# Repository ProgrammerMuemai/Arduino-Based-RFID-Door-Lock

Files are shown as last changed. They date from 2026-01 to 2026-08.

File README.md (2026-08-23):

# Arduino-Based-RFID-Door-Lock
ดูวีดีโอการทำงานได้ที่
https://youtu.be/LQMiO3PaC_U

# RFID Door Lock System with Arduino UNO

ระบบควบคุมประตูด้วยบัตร RFID โดยใช้ **Arduino UNO**, **MFRC522**, **LCD I2C** และ **Relay / SSR**

ระบบตรวจสอบสิทธิ์จาก UID ของบัตร RFID รองรับบัตรได้หลายใบ พร้อมปุ่ม **LOCK / UNLOCK แบบ Manual** และระบบ **Auto Lock หลังปลดล็อก 5 วินาที**

---

## 🔐 Features

- รองรับบัตร RFID หลายใบด้วย UID แบบ 4-byte
- ตรวจสอบสิทธิ์จาก UID ของบัตร
- แสดงสถานะผ่านจอ LCD 16x2 แบบ I2C
- ควบคุมกลอนประตูแม่เหล็ก (Magnetic Door Lock)
- รองรับ Relay / SSR
- ปุ่มกด LOCK / UNLOCK แบบ Manual
- ปุ่มต่อแบบ Pull-down
- มีระบบ Debounce ป้องกันปุ่มเด้ง
- กด UNLOCK แล้วล็อกกลับอัตโนมัติภายใน 5 วินาที
- แตะบัตรที่ได้รับอนุญาตแล้วปลดล็อก 5 วินาที
- LCD แสดงเวลานับถอยหลังจนกว่าจะ LOCK
- สามารถกด LOCK เพื่อขัดจังหวะและล็อกทันทีได้
- สามารถกด UNLOCK ซ้ำเพื่อเริ่มนับเวลา 5 วินาทีใหม่
- สามารถแตะบัตร RFID ขณะกำลังนับถอยหลังได้
- แตะบัตรที่ได้รับอนุญาตซ้ำ จะเริ่มนับ 5 วินาทีใหม่
- บัตรที่ไม่ได้รับอนุญาตจะไม่สามารถปลดล็อกได้
- แสดง UID ทั้ง HEX และ DEC ผ่าน Serial Monitor
- เพิ่มบัตรใหม่ใน `ALLOW_LIST` ได้ง่าย
- ใช้ `millis()` สำหรับ Auto Lock ทำให้ระบบไม่ค้างระหว่างนับเวลา

---

## 🧰 Hardware Required

- Arduino UNO
- MFRC522 RFID Reader
- RFID Card / Key Tag
- LCD 16x2 I2C
- Relay Module หรือ SSR
- Magnetic Door Lock 12V
- Buzzer
- Push Button x2
  - LOCK
  - UNLOCK
- Resistor สำหรับ Pull-down ปุ่มกด
- Power Supply 12V
- สาย Jumper
- Breadboard หรือ PCB ตามรูปแบบงาน

> สำหรับ Magnetic Door Lock ควรเลือก Power Supply ที่มีกระแสเพียงพอกับกลอนประตูที่ใช้งานจริง  
> โดยทั่วไปแนะนำอย่างน้อยประมาณ **12V 3A** หากใช้ร่วมกับอุปกรณ์อื่นในระบบ

---

## ⚠️ Important: MFRC522 Voltage

MFRC522 ใช้แรงดันไฟประมาณ **3.3V**

ควรต่อ:

```text
MFRC522 VCC -> Arduino 3.3V
```

ไม่ควรต่อ VCC ของ MFRC522 เข้ากับ 5V โดยตรง

---

## 🔌 Pin Configuration

| Device | Arduino UNO Pin |
|---|---:|
| MFRC522 SDA / SS | D10 |
| MFRC522 RST | D9 |
| MFRC522 MOSI | D11 |
| MFRC522 MISO | D12 |
| MFRC522 SCK | D13 |
| Relay / SSR | D2 |
| Buzzer | D3 |
| Unlock Button | D4 |
| Lock Button | D5 |
| LCD SDA | A4 |
| LCD SCL | A5 |

---

## 📡 MFRC522 Wiring

| MFRC522 | Arduino UNO |
|---|---|
| SDA / SS | D10 |
| SCK | D13 |
| MOSI | D11 |
| MISO | D12 |
| IRQ | Not Connected |
| GND | GND |
| RST | D9 |
| 3.3V | 3.3V |

---

## 🖥 LCD I2C Wiring

| LCD I2C | Arduino UNO |
|---|---|
| VCC | 5V |
| GND | GND |
| SDA | A4 |
| SCL | A5 |

LCD ที่ใช้ในโปรเจกต์นี้:

```cpp
LiquidCrystal_I2C lcd(0x27, 16, 2);
```

ดังนั้น I2C Address คือ:

```text
0x27
```

หากจอไม่แสดงผล อาจต้องตรวจสอบ I2C Address ของจอที่ใช้งานจริง

---

## 🔘 Push Button Wiring

ระบบใช้ปุ่มกดแบบ **Pull-down**

สถานะของปุ่ม:

```text
ไม่กด = LOW
กด     = HIGH
```

ขาที่ใช้:

```text
UNLOCK Button -> D4
LOCK Button   -> D5
```

ตัวอย่างการต่อปุ่ม:

```text
5V
 |
 |
[ Push Button ]
 |
 +---------- Arduino Input
 |
[ 10KΩ ]
 |
GND
```

---

## ⚡ Relay / SSR Logic

ระบบปัจจุบันกำหนด Logic ของขา D2 ดังนี้:

```cpp
#define RELAY_LOCK   LOW
#define RELAY_UNLOCK HIGH
```

ดังนั้น:

| Arduino D2 | Door State |
|---|---|
| LOW | 🔒 LOCK |
| HIGH | 🔓 UNLOCK |

หรือสรุปง่าย ๆ:

```text
LOW  = LOCK
HIGH = UNLOCK
```

> **หมายเหตุ:** Relay หรือ SSR แต่ละรุ่นอาจมี Logic การ Trigger แตกต่างกัน  
> ควรทดสอบโมดูลที่ใช้งานจริงก่อนเชื่อมต่อกับ Magnetic Door Lock

---

## 🧠 How It Works

### 1. เปิดเครื่อง

เมื่อเปิดระบบ Arduino จะกำหนดสถานะเริ่มต้นเป็น:

```text
LOCK
```

และ LCD จะแสดง:

```text
    WELCOME
TAP CARD TO OPEN
```

---

### 2. แตะบัตร RFID

Arduino จะอ่าน UID ของบัตรจาก MFRC522 และนำไปเปรียบเทียบกับรายการ:

```cpp
ALLOW_LIST
```

---

### 3. ถ้าบัตรได้รับอนุญาต

ระบบจะ:

1. ปลดล็อกประตู
2. ส่งเสียง Beep
3. แสดงสถานะ `UNLOCK` บน LCD
4. เริ่มนับถอยหลัง 5 วินาที
5. เมื่อครบเวลา ระบบจะ LOCK อัตโนมัติ
6. LCD กลับไปหน้า WELCOME

ตัวอย่าง:

```text
  >> UNLOCK <<
Lock in: 5 sec
```

จากนั้นจะนับ:

```text
Lock in: 4 sec
Lock in: 3 sec
Lock in: 2 sec
Lock in: 1 sec
```

เมื่อครบเวลา:

```text
LOCK
```

และกลับไป:

```text
    WELCOME
TAP CARD TO OPEN
```

---

### 4. ถ้าบัตรไม่ได้รับอนุญาต

ระบบจะ:

- ไม่ปลดล็อกประตู
- ส่งเสียงเตือน 2 ครั้ง
- แสดงข้อความบน LCD

```text
 ACCESS DENIED!
 INVALID CARD
```

จากนั้นกลับไปหน้า WELCOME

---

## ⏱ Auto Lock System

เวลาปลดล็อกถูกกำหนดไว้ที่:

```cpp
const unsigned long UNLOCK_TIME = 5000;
```

ค่า `5000` หมายถึง:

```text
5000 milliseconds = 5 seconds
```

หากต้องการปลดล็อก 10 วินาที สามารถเปลี่ยนเป็น:

```cpp
const unsigned long UNLOCK_TIME = 10000;
```

---

## 🔄 Non-Blocking Countdown

ระบบใช้ `millis()` สำหรับนับเวลาแทนการใช้:

```cpp
delay(5000);
```

ข้อดีคือ Arduino ยังสามารถทำงานอื่นได้ระหว่างนับเวลา เช่น:

- อ่าน RFID
- อ่านปุ่ม LOCK
- อ่านปุ่ม UNLOCK
- อัปเดต LCD
- ตรวจสอบ Auto Lock

ทำให้ระบบตอบสนองได้ตลอดเวลา

---

## 🔘 Manual LOCK Button

เมื่อกดปุ่ม LOCK:

```text
D5 = HIGH
```

ระบบจะ LOCK ทันที

แม้ว่าขณะนั้นระบบกำลังนับถอยหลัง 5 วินาทีอยู่ก็ตาม

ตัวอย่าง:

```text
UNLOCK
5 sec
4 sec
```

หากกด LOCK:

```text
LOCK
```

ทันทีโดยไม่ต้องรอให้ครบ 5 วินาที

---

## 🔓 Manual UNLOCK Button

เมื่อกดปุ่ม UNLOCK:

```text
D4 = HIGH
```

ระบบจะ:

1. UNLOCK
2. เริ่มนับเวลา 5 วินาที
3. LCD แสดง Countdown
4. LOCK อัตโนมัติเมื่อครบเวลา

หากกด UNLOCK ซ้ำระหว่างที่กำลังปลดล็อก:

```text
5 sec
4 sec
3 sec
```

ระบบจะเริ่มนับใหม่:

```text
5 sec
```

---

## 💳 RFID During Unlock Countdown

ระหว่างที่ประตูกำลัง UNLOCK ระบบยังสามารถอ่าน RFID ได้

ตัวอย่าง:

```text
UNLOCK
Lock in: 3 sec
```

หากแตะบัตรที่ได้รับอนุญาตอีกครั้ง ระบบจะเริ่มนับใหม่:

```text
UNLOCK
Lock in: 5 sec
```

---

## 🔑 Authorized RFID Card

บัตรที่กำหนดไว้ในระบบปัจจุบัน:

### HEX

```text
C0 58 BE 13
```

### DEC

```text
192 88 190 19
```

ในโค้ดจะเขียนเป็น:

```cpp
const byte ALLOW_LIST[][4] = {

  {192, 88, 190, 19},

};
```

---

## ➕ How to Add New RFID Card

### Step 1

เชื่อมต่อ Arduino UNO กับคอมพิวเตอร์

---

### Step 2

เปิด Arduino IDE และเปิด:

```text
Tools -> Serial Monitor
```

ตั้ง Baud Rate เป็น:

```text
9600
```

---

### Step 3

แตะบัตร RFID ที่ต้องการเพิ่ม

Serial Monitor จะแสดงประมาณ:

```text
UID HEX = C0 58 BE 13
UID DEC = 192 88 190 19
```

---

### Step 4

นำค่า DEC ไปเพิ่มใน `ALLOW_LIST`

ตัวอย่างเพิ่ม 3 ใบ:

```cpp
const byte ALLOW_LIST[][4] = {

  {192, 88, 190, 19},     // Card 1
  {12, 34, 56, 78},       // Card 2
  {100, 120, 130, 140}    // Card 3

};
```

ไม่จำเป็นต้องแก้ค่า `ALLOW_COUNT` เพราะโปรแกรมจะคำนวณจำนวนบัตรให้อัตโนมัติ:

```cpp
const byte ALLOW_COUNT =
  sizeof(ALLOW_LIST) / sizeof(ALLOW_LIST[0]);
```

---

## 🖥 Serial Monitor

ตั้ง Serial Monitor ที่:

```text
9600 baud
```

ตัวอย่างเมื่อแตะบัตร:

```text
----------------------------
UID HEX = C0 58 BE 13
UID DEC = 192 88 190 19
ACCESS = GRANTED
DOOR = UNLOCK
```

เมื่อครบ 5 วินาที:

```text
AUTO LOCK AFTER 5 SEC
DOOR = LOCK
```

หากเป็นบัตรที่ไม่ได้รับอนุญาต:

```text
UID HEX = XX XX XX XX
UID DEC = XXX XXX XXX XXX
ACCESS = DENIED
```

---

## 📚 Required Arduino Libraries

โปรเจกต์นี้ใช้ Library ดังต่อไปนี้:

### MFRC522

```cpp
#include <MFRC522.h>
```

สามารถติดตั้งผ่าน Arduino IDE:

```text
Sketch
-> Include Library
-> Manage Libraries
```

ค้นหา:

```text
MFRC522
```

---

### LiquidCrystal I2C

```cpp
#include <LiquidCrystal_I2C.h>
```

ค้นหาใน Library Manager:

```text
LiquidCrystal I2C
```

---

### SPI

```cpp
#include <SPI.h>
```

เป็น Library มาตรฐานของ Arduino

---

### Wire

```cpp
#include <Wire.h>
```

เป็น Library มาตรฐานของ Arduino

---

## 📋 System Logic

| Event | Result |
|---|---|
| Power ON | 🔒 LOCK |
| Authorized RFID Card | 🔓 UNLOCK 5 sec |
| Unauthorized RFID Card | ❌ ACCESS DENIED |
| Press UNLOCK | 🔓 UNLOCK 5 sec |
| Press LOCK | 🔒 LOCK immediately |
| Unlock timeout | 🔒 AUTO LOCK |
| Authorized card during countdown | 🔄 Restart 5 sec |
| UNLOCK button during countdown | 🔄 Restart 5 sec |
| LOCK button during countdown | 🔒 LOCK immediately |

---

## 🔒 Default Safety State

เมื่อ Arduino เปิดเครื่อง ระบบจะกำหนดประตูเป็น:

```text
LOCK
```

ก่อนเริ่มต้น RFID และ LCD

ตัวอย่าง Logic:

```cpp
digitalWrite(RELAY, RELAY_LOCK);
```

โดย:

```cpp
#define RELAY_LOCK LOW
```

ดังนั้นระบบจะเริ่มต้นในสถานะ LOCK เสมอตาม Logic ของฮาร์ดแวร์ชุดนี้

---

## 🛠 Troubleshooting

### RFID อ่านบัตรไม่ได้

ตรวจสอบ:

- MFRC522 ใช้ไฟ 3.3V
- SDA ต่อ D10
- RST ต่อ D9
- MOSI ต่อ D11
- MISO ต่อ D12
- SCK ต่อ D13
- GND ต้องต่อร่วมกัน

---

### LCD ไม่แสดงผล

ตรวจสอบ:

```text
SDA -> A4
SCL -> A5
```

และตรวจสอบ I2C Address

ค่าปัจจุบัน:

```text
0x27
```

---

### Relay / SSR ทำงานกลับด้าน

หากระบบจริงทำงานตรงข้าม เช่น:

```text
LOW  = UNLOCK
HIGH = LOCK
```

ให้สลับค่า:

```cpp
#define RELAY_LOCK   HIGH
#define RELAY_UNLOCK LOW
```

---

### ปุ่ม LOCK / UNLOCK ทำงานสลับกัน

ตรวจสอบว่าสายต่อถูกต้อง:

```text
UNLOCK -> D4
LOCK   -> D5
```

---

### RFID หลุดหรืออ่านไม่ได้เมื่อกลอนทำงาน

กลอนแม่เหล็กและวงจร Relay อาจสร้าง Noise รบกวน Arduino หรือ MFRC522

แนวทางแก้ไข:

- แยกสายไฟกลอนออกจากสายสัญญาณ RFID
- ใช้ Power Supply ที่มีกระแสเพียงพอ
- ต่อ GND ให้เหมาะสม
- เพิ่ม Capacitor ใกล้ Arduino / MFRC522
- หากใช้ Relay กับโหลด DC แบบขดลวด ควรมีวงจรป้องกันแรงดันย้อนกลับตามชนิดวงจร
- หลีกเลี่ยงการเดินสาย MFRC522 ใกล้สายกำลังของ Magnetic Lock

---

## ⚠️ Security Note

ระบบนี้ตรวจสอบสิทธิ์จาก **UID ของบัตร RFID**

เหมาะสำหรับ:

- โปรเจกต์ Arduino
- ระบบทดลอง
- ห้อง Workshop
- ตู้เก็บอุปกรณ์
- ระบบควบคุมการเข้าออกที่ไม่ต้องการ Security ระดับสูง

UID เพียงอย่างเดียวไม่ควรถูกใช้เป็นระบบรักษาความปลอดภัยระดับสูง เนื่องจากบัตร RFID บางประเภทสามารถจำลองหรือคัดลอก UID ได้

---

## 🚀 Future Improvements

สามารถพัฒนาระบบเพิ่มเติมได้ เช่น:

- เพิ่ม Admin Card
- เพิ่มโหมด Add / Delete Card
- บันทึก UID ลง EEPROM
- เพิ่ม RTC สำหรับบันทึกเวลาเข้าออก
- เพิ่ม SD Card สำหรับเก็บ Log
- เพิ่ม ESP32
- เชื่อมต่อ Wi-Fi
- แจ้งเตือนผ่าน LINE / Telegram
- เชื่อมต่อ Home Assistant
- เพิ่ม Keypad
- เพิ่ม Fingerprint Sensor
- เพิ่ม Door Sensor
- เพิ่ม Exit Button
- เพิ่มระบบตรวจสอบว่าประตูปิดจริงหรือไม่
- เพิ่มระบบ Web Dashboard

---

## 👨‍💻 Author

Developed by **MengDIY**

Arduino RFID Door Lock System

---

## 📄 License

This project is intended for educational and DIY purposes.

You are free to study, modify, and improve the project for your own use.

---

⭐ หากโปรเจกต์นี้มีประโยชน์ สามารถกด **Star** Repository เพื่อสนับสนุนโปรเจกต์ได้

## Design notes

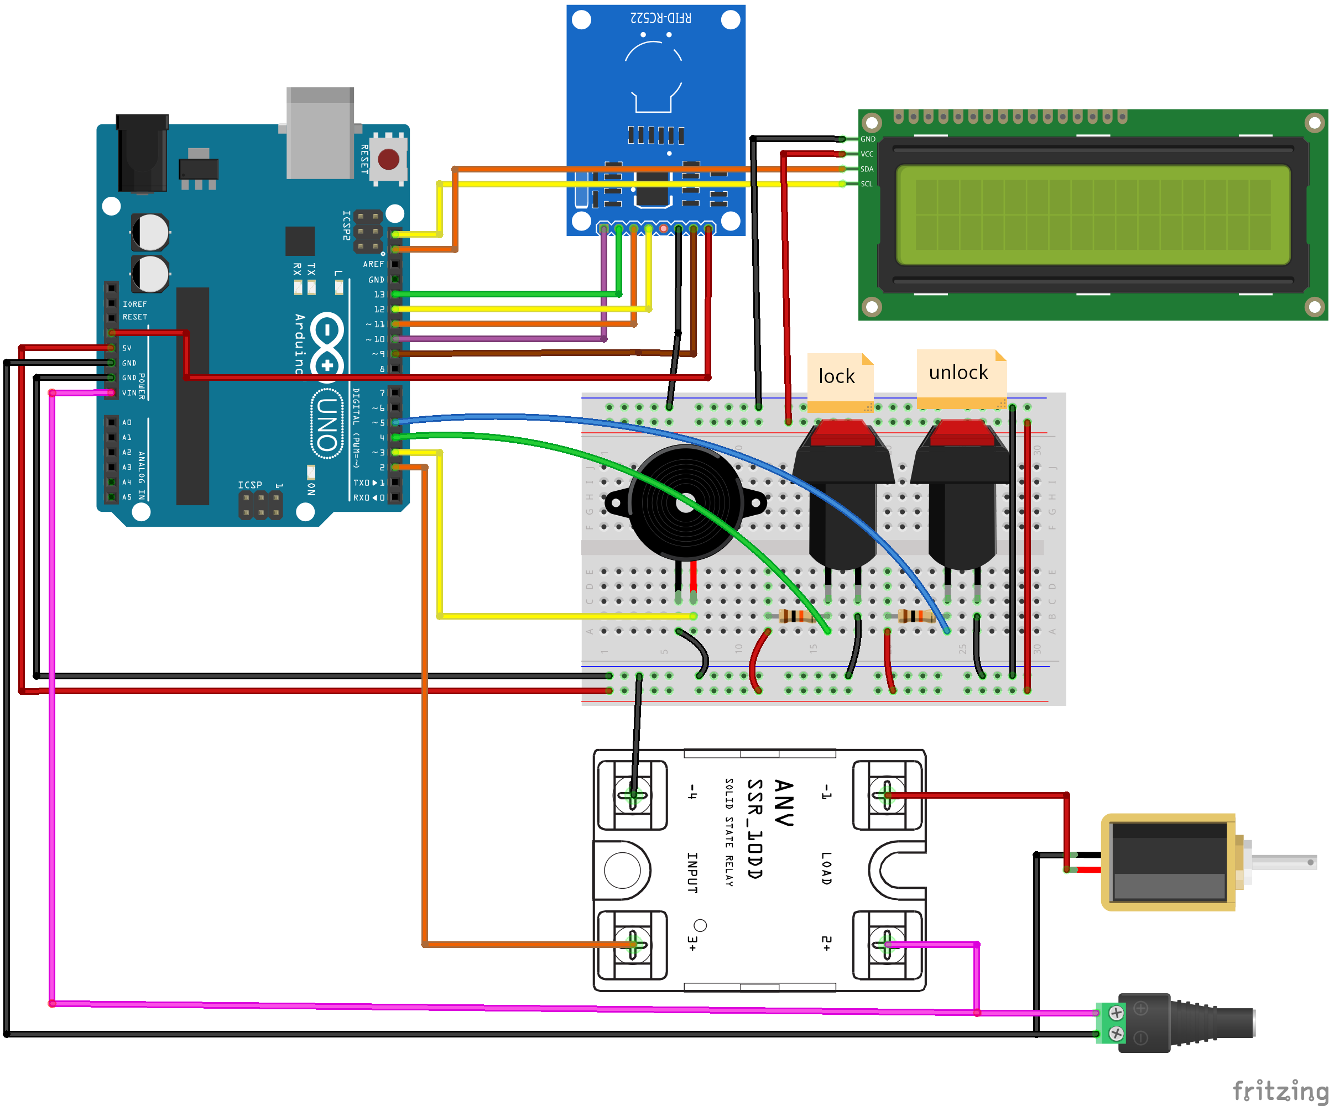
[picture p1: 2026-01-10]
Circuit/circuit_bb.png

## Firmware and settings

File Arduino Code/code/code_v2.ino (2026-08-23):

// ===================== ไลบรารี =====================
#include <SPI.h>
#include <MFRC522.h>
#include <Wire.h>
#include <LiquidCrystal_I2C.h>

// ===================== กำหนดขา =====================
#define SS_PIN 10
#define RST_PIN 9

#define RELAY 2
#define BUZZER 3

// จากการทดสอบปุ่มของคุณ
#define UNLOCK 4
#define LOCK   5

// =====================================================
//                 LOGIC ของ SSR
// =====================================================
// LOW  = LOCK
// HIGH = UNLOCK
#define RELAY_LOCK   LOW
#define RELAY_UNLOCK HIGH

// ===================== Object =====================
LiquidCrystal_I2C lcd(0x27, 16, 2);
MFRC522 rfid(SS_PIN, RST_PIN);

// =====================================================
//               UID บัตรที่อนุญาต
// =====================================================
// HEX = C0 58 BE 13
// DEC = 192 88 190 19

const byte ALLOW_LIST[][4] = {

  {192, 88, 190, 19},

  // เพิ่มบัตรใบอื่นได้ เช่น
  // {12, 34, 56, 78},
  // {100, 120, 130, 140},

};

const byte ALLOW_COUNT =
  sizeof(ALLOW_LIST) / sizeof(ALLOW_LIST[0]);

// =====================================================
//                  เวลา UNLOCK
// =====================================================

const unsigned long UNLOCK_TIME = 5000;

unsigned long unlockStartMs = 0;

bool doorUnlocked = false;

// =====================================================
//                 Boot / Debounce
// =====================================================

unsigned long bootMs = 0;

const unsigned long BOOT_IGNORE_MS = 1000;
const unsigned long DEBOUNCE_MS = 120;

unsigned long lastBtnMs = 0;

bool lastLock = LOW;
bool lastUnlock = LOW;

// สำหรับอัปเดตเลข Countdown
int lastCountdown = -1;

// =====================================================
//                  ตรวจสอบ UID
// =====================================================

bool isAllowedUID(const byte *uid, byte size) {

  // UID ต้องเป็น 4 byte
  if (size != 4) {
    return false;
  }

  // ตรวจทุกบัตรใน Allow List
  for (byte card = 0; card < ALLOW_COUNT; card++) {

    bool match = true;

    for (byte i = 0; i < 4; i++) {

      if (uid[i] != ALLOW_LIST[card][i]) {

        match = false;
        break;
      }
    }

    if (match) {
      return true;
    }
  }

  return false;
}

// =====================================================
//                    หน้า HOME
// =====================================================

void lcdHomeScreen() {

  lcd.clear();

  lcd.setCursor(4, 0);
  lcd.print("WELCOME");

  lcd.setCursor(0, 1);
  lcd.print("TAP CARD TO OPEN");
}

// =====================================================
//                  หน้า UNLOCK
// =====================================================

void lcdUnlockScreen() {

  lcd.clear();

  lcd.setCursor(2, 0);
  lcd.print(">> UNLOCK <<");

  lcd.setCursor(0, 1);
  lcd.print("Lock in: 5 sec");

  lastCountdown = 5;
}

// =====================================================
//                       LOCK
// =====================================================

void lockDoor() {

  digitalWrite(RELAY, RELAY_LOCK);

  doorUnlocked = false;

  lastCountdown = -1;

  Serial.println(F("DOOR = LOCK"));

  lcdHomeScreen();
}

// =====================================================
//                      UNLOCK
// =====================================================

void unlockDoor() {

  digitalWrite(RELAY, RELAY_UNLOCK);

  doorUnlocked = true;

  // เริ่มนับ 5 วินาทีใหม่ทุกครั้ง
  unlockStartMs = millis();

  Serial.println(F("DOOR = UNLOCK"));
}

// =====================================================
//                  เสียงบัตรผ่าน
// =====================================================

void beepOK() {

  digitalWrite(BUZZER, HIGH);
  delay(80);
  digitalWrite(BUZZER, LOW);
}

// =====================================================
//                  เสียงบัตรไม่ผ่าน
// =====================================================

void beepDenied() {

  digitalWrite(BUZZER, HIGH);
  delay(60);

  digitalWrite(BUZZER, LOW);
  delay(60);

  digitalWrite(BUZZER, HIGH);
  delay(60);

  digitalWrite(BUZZER, LOW);
}

// =====================================================
//                       SETUP
// =====================================================

void setup() {

  Serial.begin(9600);

  // ===================================================
  // I/O
  // ===================================================

  pinMode(RELAY, OUTPUT);
  pinMode(BUZZER, OUTPUT);

  // ปุ่มใช้ Pull-down ภายนอก
  // ปล่อย = LOW
  // กด = HIGH
  pinMode(LOCK, INPUT);
  pinMode(UNLOCK, INPUT);

  digitalWrite(BUZZER, LOW);

  // ===================================================
  // เปิดเครื่องมาให้ LOCK ก่อนเสมอ
  // ===================================================

  digitalWrite(RELAY, RELAY_LOCK);

  doorUnlocked = false;

  delay(200);

  digitalWrite(RELAY, RELAY_LOCK);

  // ===================================================
  // SPI
  // ===================================================

  pinMode(SS_PIN, OUTPUT);
  digitalWrite(SS_PIN, HIGH);

  SPI.begin();

  // ===================================================
  // RFID
  // ===================================================

  rfid.PCD_Init();

  delay(50);

  // ===================================================
  // LCD
  // ===================================================

  lcd.init();
  lcd.backlight();

  lcdHomeScreen();

  // ===================================================
  // เวลาเริ่มระบบ
  // ===================================================

  bootMs = millis();

  // ===================================================
  // Serial Debug
  // ===================================================

  Serial.println();
  Serial.println(F("============================"));
  Serial.println(F(" RFID ACCESS CONTROL READY"));
  Serial.println(F("============================"));

  Serial.println(F("SSR Logic:"));
  Serial.println(F("LOW  = LOCK"));
  Serial.println(F("HIGH = UNLOCK"));

  Serial.println();

  Serial.println(F("Authorized Card:"));
  Serial.println(F("HEX = C0 58 BE 13"));
  Serial.println(F("DEC = 192 88 190 19"));

  Serial.print(F("Allow cards = "));
  Serial.println(ALLOW_COUNT);

  Serial.println();
  Serial.println(F("Default = LOCK"));
}

// =====================================================
//                         LOOP
// =====================================================

void loop() {

  // ===================================================
  //            AUTO LOCK หลัง 5 วินาที
  // ===================================================

  if (doorUnlocked) {

    unsigned long elapsed =
      millis() - unlockStartMs;

    // =================================================
    // คำนวณเวลาที่เหลือ
    // =================================================

    int remaining;

    if (elapsed >= UNLOCK_TIME) {

      remaining = 0;

    } else {

      remaining =
        (UNLOCK_TIME - elapsed + 999) / 1000;
    }

    // =================================================
    // อัปเดต LCD เฉพาะตอนเลขเปลี่ยน
    // =================================================

    if (remaining != lastCountdown) {

      lastCountdown = remaining;

      lcd.setCursor(9, 1);

      // ลบข้อมูลเก่า
      lcd.print("       ");

      lcd.setCursor(9, 1);

      lcd.print(remaining);
      lcd.print(" sec");
    }

    // =================================================
    // ครบ 5 วินาที
    // =================================================

    if (elapsed >= UNLOCK_TIME) {

      Serial.println(F("AUTO LOCK AFTER 5 SEC"));

      lockDoor();
    }
  }

  // ===================================================
  //                   อ่านปุ่ม
  // ===================================================

  bool nowLock =
    digitalRead(LOCK);

  bool nowUnlock =
    digitalRead(UNLOCK);

  // ไม่รับปุ่มช่วงบูต 1 วินาที
  if (millis() - bootMs >= BOOT_IGNORE_MS) {

    if (millis() - lastBtnMs >= DEBOUNCE_MS) {

      // =================================================
      //                   ปุ่ม LOCK
      // =================================================

      if (nowLock == HIGH &&
          lastLock == LOW) {

        Serial.println(F("BUTTON = LOCK"));

        // ล็อกทันที
        lockDoor();

        beepOK();

        lastBtnMs = millis();
      }

      // =================================================
      //                  ปุ่ม UNLOCK
      // =================================================

      if (nowUnlock == HIGH &&
          lastUnlock == LOW) {

        Serial.println(F("BUTTON = UNLOCK"));

        // ปลดล็อก
        unlockDoor();

        // เริ่มหน้าจอนับ 5 วินาที
        lcdUnlockScreen();

        beepOK();

        lastBtnMs = millis();
      }
    }
  }

  // บันทึกสถานะปุ่มล่าสุด
  lastLock = nowLock;
  lastUnlock = nowUnlock;

  // ===================================================
  //                      RFID
  // ===================================================

  if (rfid.PICC_IsNewCardPresent()) {

    if (rfid.PICC_ReadCardSerial()) {

      Serial.println();
      Serial.println(F("----------------------------"));

      // =================================================
      // แสดง UID HEX
      // =================================================

      Serial.print(F("UID HEX = "));

      printHex(
        rfid.uid.uidByte,
        rfid.uid.size
      );

      Serial.println();

      // =================================================
      // แสดง UID DEC
      // =================================================

      Serial.print(F("UID DEC = "));

      printDec(
        rfid.uid.uidByte,
        rfid.uid.size
      );

      Serial.println();

      // =================================================
      // ตรวจสอบ UID
      // =================================================

      bool allowed =
        isAllowedUID(
          rfid.uid.uidByte,
          rfid.uid.size
        );

      // =================================================
      //                    บัตรผ่าน
      // =================================================

      if (allowed) {

        Serial.println(F("ACCESS = GRANTED"));

        // -----------------------------------------------
        // ปลดล็อก
        //
        // ถ้ากำลัง Unlock อยู่แล้ว
        // การแตะบัตรซ้ำจะเริ่มนับ 5 วินาทีใหม่
        // -----------------------------------------------

        unlockDoor();

        lcdUnlockScreen();

        beepOK();
      }

      // =================================================
      //                   บัตรไม่ผ่าน
      // =================================================

      else {

        Serial.println(F("ACCESS = DENIED"));

        beepDenied();

        // ------------------------------------------------
        // ถ้าประตู LOCK อยู่
        // แสดง Access Denied
        // ------------------------------------------------

        if (!doorUnlocked) {

          lcd.clear();

          lcd.setCursor(1, 0);
          lcd.print("ACCESS DENIED!");

          lcd.setCursor(1, 1);
          lcd.print("INVALID CARD");

          delay(700);

          lcdHomeScreen();
        }

        // ------------------------------------------------
        // ถ้ากำลัง UNLOCK อยู่
        // บัตรผิดจะไม่ไปต่อเวลา
        // และไม่เปลี่ยนสถานะประตู
        //
        // ระบบจะนับ 5 วินาทีเดิมต่อ
        // ------------------------------------------------
      }

      // =================================================
      // จบ RFID Session
      // =================================================

      rfid.PICC_HaltA();
      rfid.PCD_StopCrypto1();
    }
  }
}

// =====================================================
//                    แสดง UID HEX
// =====================================================

void printHex(byte *buffer, byte bufferSize) {

  for (byte i = 0; i < bufferSize; i++) {

    if (buffer[i] < 0x10) {
      Serial.print(" 0");
    } else {
      Serial.print(" ");
    }

    Serial.print(buffer[i], HEX);
  }
}

// =====================================================
//                    แสดง UID DEC
// =====================================================

void printDec(byte *buffer, byte bufferSize) {

  for (byte i = 0; i < bufferSize; i++) {

    Serial.print(" ");
    Serial.print(buffer[i], DEC);
  }
}

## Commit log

2022-09-24 new project
    add
    [door lock.fzz]
2026-01-09 Update components list in README
    Remove Buck Converter mention from components list
